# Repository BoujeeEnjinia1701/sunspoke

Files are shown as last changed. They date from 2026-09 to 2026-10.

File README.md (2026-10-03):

# SunSpoke

     

**Area:** Mobility and Logistics · **TRL:** 3 of 9 (proof of concept on paper) · **Value-engineering target:** USD 250 for the bike kit (estimated USD 208; solar set costed separately; pack priced in SwapCell) · **Difficulty:** 3 of 5

Open, bolt-on electric conversion kit for existing steel bicycles, serviceable by local bike mechanics and charged from a single 100 W solar panel or a shared village hub, using a SwapCell-compatible battery.

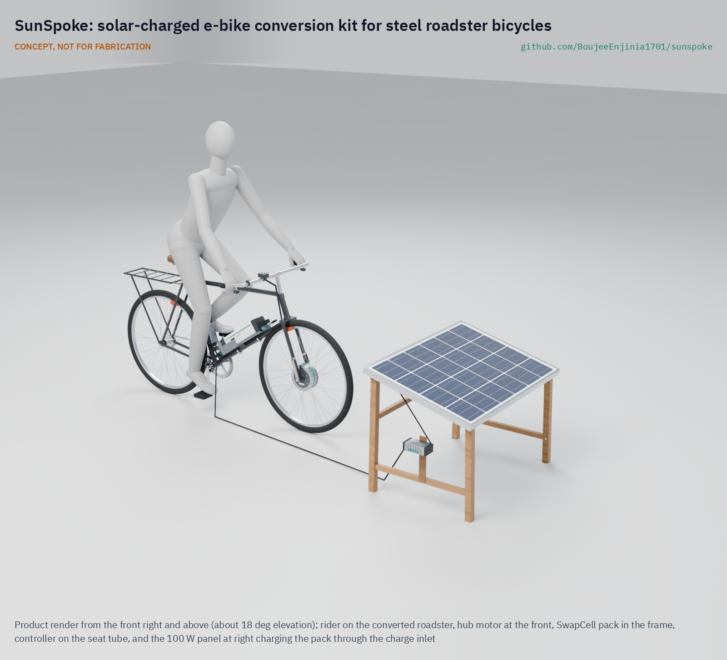
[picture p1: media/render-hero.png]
SunSpoke: solar-charged e-bike conversion kit for steel roadster bicycles, product render


[Exploded render](media/render-exploded.png) · [Detail render](media/render-detail.png) · [Interactive 3D model](media/viewer.html) · [Concept blueprint (PDF)](media/concept-blueprint.pdf) · [General arrangement SSP-DWG-001 (PDF)](cad/drawings/SSP-DWG-001.pdf) · [Sizing note SSP-CAL-001](docs/04-calcs/01-sizing.md) · [Prototype build plan](docs/05-build-plan.md) · [Design decisions](docs/06-design-decisions.md) · [Review note](docs/REVIEW.md)

## Concept rationale

The cheapest vehicle a rural household can electrify is the one it already owns. A bolt-on front hub kit leaves the roadster's chain, rear brake and carrier untouched, so the bicycle keeps working as a bicycle if anything electrical fails, and the parts that do fail are generic e-bike parts that a roadside mechanic can swap with spanners and a multimeter. Charging from one 100 W panel, or by swapping a shared SwapCell pack at a village hub, removes the dependence on a grid that many riders do not have.

Keeping the design open matters for the same reason. Closed kits lock the local mechanic out of repairs and settings; published drawings, a priced bill of materials and a plain wiring scheme let a workshop fit, service and adapt the kit, and let a small fabricator make the cradle and panel stand locally. Every part is chosen so the conversion can be done in a garage with hand tools and no welding.

## Burning platform

In 2023, 666 million people still had no access to electricity, and 85 percent of them, about 566 million, lived in sub-Saharan Africa ([World Bank, Tracking SDG 7: The Energy Progress Report 2025](https://www.worldbank.org/en/news/press-release/2025/06/25/energy-access-has-improved-yet-international-financial-support-still-needed-to-boost-progress-and-address-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)). Eighteen of the 20 countries with the largest access deficits are in that region. These are the same places where the unpowered steel roadster is the working vehicle for carrying people, water and produce over dirt roads.

For these riders, an e-bike that must be charged from a wall socket is not an option, and a new e-bike costs far more than the bicycle they already have. Assist that runs on a small solar panel and fits the existing bicycle turns hours of pushing a loaded bike uphill into a ride, without waiting for the grid to arrive.

## Where it could be used

### By industry

| Industry | Use |
| --- | --- |
| Smallholder agriculture | Carrying produce, feed and water from farm to market on loaded roadsters |
| Community health services | Longer, more reliable daily rounds for health workers on rural routes |
| Informal transport | Bicycle taxis and goods carriers that already run on roadsters |
| Bicycle repair and retail | A new fitting and service trade for roadside mechanics |
| Off-grid energy | Village solar hubs that charge and swap SwapCell packs as a service |
| Last-mile logistics | Low-cost cargo delivery in towns where grid charging is unreliable |

### By country or region

| Country or region | Why it matters there |
| --- | --- |
| Uganda and Kenya | Uganda's *Daily Monitor* reports that the boda-boda began with bicycle riders in Busia, on the Kenya-Uganda border, who called "border, border" to find passengers before the trade moved to motorcycles ([Daily Monitor, 2017](https://www.monitor.co.ug/uganda/news/national/boda-boda-makes-its-way-to-oxford-advanced-learners-dictionary-1702836)); an assist kit fits the bicycle taxis and carriers that started that trade |
| Wider sub-Saharan Africa | The region is home to 85 percent of the 666 million people without electricity and holds 18 of the 20 largest national access deficits ([World Bank, 2025](https://www.worldbank.org/en/news/press-release/2025/06/25/energy-access-has-improved-yet-international-financial-support-still-needed-to-boost-progress-and-address-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)); solar charging suits routes far from the grid |
| India | Bicycle-owning households rose from 84 million in 2001 to 111 million in 2011, and an estimated 21 percent of rural work trips are made by bicycle ([TERI, *Benefits of Cycling in India*, 2020](https://www.teriin.org/sites/default/files/2020-06/benefits-cycling-report.pdf), drawing on Census of India data); rural riders are a large base for a low-cost conversion |
| Haiti | The electricity access rate was estimated at about 47.1 percent in 2021, and the World Bank is financing solar mini-grids and standalone solar systems to extend access ([World Bank, 2024](https://www.worldbank.org/en/news/press-release/2024/10/18/world-bank-to-support-sustainable-energy-access-in-haiti)); a kit that charges from its own panel does not wait for the grid |
| Netherlands | About 56 percent of the 804,000 new bicycles sold in 2023 were e-bikes ([BOVAG and RAI Vereniging, February 26, 2024](https://www.bovag.nl/pers/persberichten/fietsbranche-consolideert-hoge-omzetniveau); also reported by [DutchNews.nl](https://www.dutchnews.nl/2024/11/the-dutch-are-cycling-more-and-buying-more-e-bikes/)); a conversion kit lets owners of sturdy older bicycles join that shift without buying new |

## What sparked the idea

The idea traces back to the first patented electric bicycle. On December 31, 1895, Ogden Bolton Jr. was granted US Patent 552,271 for an "electrical bicycle" with a direct-current motor built into the hub of the rear wheel ([Google Patents, US552271A](https://patents.google.com/patent/US552271A/en)). The hub motor was the first answer to adding power to a bicycle without redesigning it, and more than a century later it is still the simplest one: a motor that replaces a wheel and bolts into the frame the rider already owns. SunSpoke takes that precedent to the steel roadsters of rural Africa, with a motor a local mechanic can lace into a standard rim and a battery that charges from the sun.

## Problem

Most bicycles in rural Africa are unpowered steel roadsters, and commercial e-bikes are too costly and hard to charge where grid power is scarce. Design with, not for: requirements must come from co-design sessions and field trials with the intended users through a local partner.

## Concept

Open, bolt-on electric conversion kit for existing steel bicycles, serviceable by local bike mechanics and charged from a single 100 W solar panel or a shared village hub, using a SwapCell-compatible battery.

Full design precis: [docs/02-concept.md](docs/02-concept.md)

## Key components

- 250 W geared front hub motor wheel, 48 V
- 48 V SwapCell pack (SwapCell interface v0.3; 48 V decided by Amish, 2026-09-25)
- Sealed controller with a motor thermistor input that derates instead of cutting out (decided by Amish, 2026-09-25)
- Handlebar power switch in the SwapCell INTERLOCK loop
- Pedal-assist sensor
- SwapCell receiver cradle on V-saddles and three band clamps (no welding or drilling), with a drop-down gate and over-centre draw latch, and the host adapter
- 100 W solar panel with MPPT charger
- Weatherproof wiring harness

The working bill of materials is in [bom/bom.csv](bom/bom.csv).

## Building the prototype

The [prototype build plan](docs/05-build-plan.md) (SSP-BLD-001) shows, in pictures drawn from the model, how each part is made and how it fits the next, then how the kit goes onto a donor roadster in twelve steps and the solar set in three. Making the design buildable changed the concept in places (decision record [SSP-DDR-003](docs/decisions/0003-design-for-construction.md)): the cradle now sits on V-saddles with three band clamps, the pack is held by a drop-down gate and an over-centre draw latch, the torque arms are joggled to lie on the fork blades, and the panel stand is a bolted timber frame. Nothing is welded, and nothing is drilled or cut on the donor bicycle. Decisions still open are in the [design decisions register](docs/06-design-decisions.md).

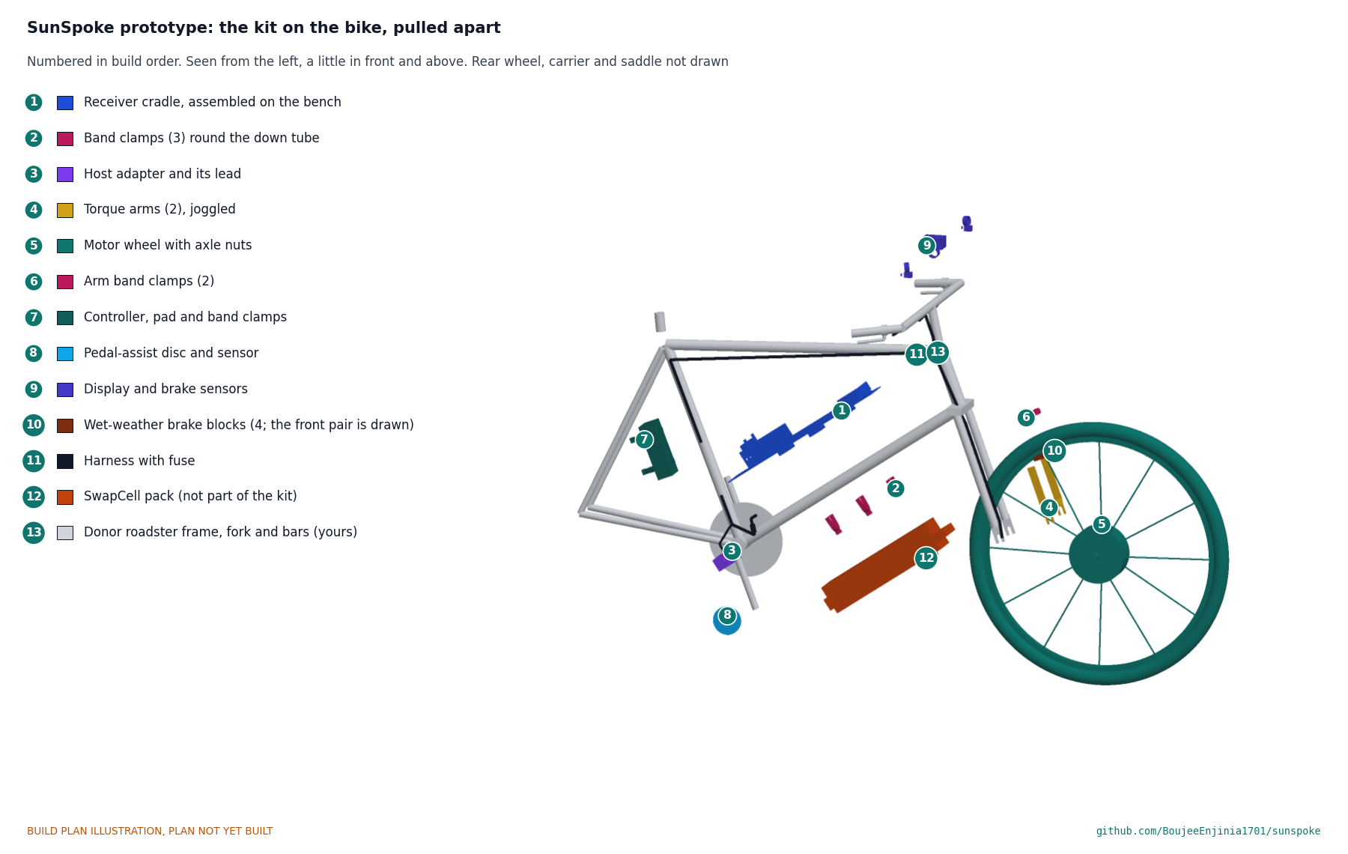
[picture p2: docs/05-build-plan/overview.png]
SunSpoke kit on the donor bicycle, pulled apart and numbered in build order


## Safety

> Check that the donor frame and fork can take a hub motor's torque; fit torque arms, and never file the fork's dropout slots: choose a donor whose slots take the motor's axle flats. Rod brakes on steel rims lose most of their grip in rain; fit the wet-weather brake blocks in the kit, and do not ride a trial bike in the wet until a wet braking test meets the target. Contains a lithium battery pack. Use a BMS with cell-level protection, fuse the pack, and charge on a non-combustible surface.

## Repository layout

| Folder | Contents |
| --- | --- |
| `docs/` | Problem, concept, requirements, calculations and design decisions |
| `cad/src/` | build123d Python source, the source of truth for all geometry |
| `cad/step/`, `cad/stl/` | Exported models for FreeCAD, other CAD tools and printing |
| `cad/drawings/` | 2D sketches and dimensioned drawings |
| `bom/` | Bill of materials |
| `electronics/` | KiCad schematics and PCB layouts |
| `firmware/` | Microcontroller code |
| `media/` | Renders, perspectives and photos |
| `build-log/` | Dated prototyping notes |

## Documentation

Controlled documents follow the portfolio [documentation standard](.kit/STANDARDS.md). Each carries a document ID (SSP-PRC-001 for the precis), a version and a revision history. Branded PDFs are built with `python .kit/render.py` and attached to GitHub Releases when a document is tagged, for example `SSP-PRC-001/v1.0`.

## Credits

Designed by Amish Chadha. See [CONTRIBUTORS.md](CONTRIBUTORS.md) for roles. To cite this design, use [CITATION.cff](CITATION.cff) (GitHub shows it as "Cite this repository").

AI assistance (Claude) was used to accelerate concept renders, prototype documentation and first-pass sizing calculations. Design direction and all decisions are Amish Chadha's, recorded in this repository's decision records (`docs/decisions/`).

## Licenses

- **Hardware** (CAD, drawings, BOM, electronics): [CERN-OHL-S v2](LICENSE)
- **Software** (firmware, scripts, notebooks): [MIT](LICENSE-SOFTWARE)

A project of the [Design Molecule](https://designmolecule.com) lab.

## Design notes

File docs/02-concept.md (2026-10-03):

---
doc_id: SSP-PRC-001
title: SunSpoke design precis
project: SunSpoke
doc_type: Design precis
version: "0.7"
status: Draft
date: '2026-10-02'
author: Amish Chadha
license: CERN-OHL-S-2.0
revisions:
- version: "0.1"
  date: '2026-09-24'
  author: Amish Chadha
  change: Initial scaffold
- version: "0.2"
  date: '2026-09-24'
  author: Amish Chadha
  change: Populate to TRL 2 (architecture, first-order numbers, fork torque, safety, media)
- version: "0.3"
  date: '2026-09-25'
  author: Amish Chadha
  change: TRL 3. Record Amish's decisions (SSP-DDR-001), build to SwapCell interface v0.3 (items W, C, V), numbers checked against SSP-CAL-001, parametric model and GA drawing SSP-DWG-001
- version: "0.4"
  date: '2026-09-25'
  author: Amish Chadha
  change: Recommendations accepted by Amish (DDR-002)
- version: "0.5"
  date: '2026-10-01'
  author: Amish Chadha
  change: "Constructable design (SSP-DDR-003): cradle on V-saddles with three band clamps, drop-down gate and draw latch, joggled torque arms, timber panel stand; figures from SSP-CAL-001 v0.3; build plan SSP-BLD-001"
- version: "0.6"
  date: '2026-10-02'
  author: Amish Chadha
  change: "Region, slot filing, reference motor and wet braking decided by Amish on 2026-10-02 (SSP-DEC-001)"
- version: "0.7"
  date: '2026-10-02'
  author: Amish Chadha
  change: "Figures from SSP-CAL-001 v0.5: wet-weather brake blocks in the kit, wet stop 11.9 m with them against a proposed 14 m wet target, added mass 6.88 kg, bike kit USD 208"
---

# SunSpoke design precis

SunSpoke converts a steel roadster bicycle into a pedal-assist e-bike with a 48 V, 250 W geared front hub motor, a sealed controller and a SwapCell pack clamped inside the main triangle, all bolted on with no welding, and charges the pack from one 100 W solar panel or a shared village hub. The sizing note SSP-CAL-001 gives about 37 km of loaded range on one pack, about 315 Wh stored per 4.5 sun-hour day from one panel (about 27 km of loaded riding), 6.88 kg of added mass, and a bike kit costing about USD 208 in parts (USD 42 under its USD 250 value-engineering target), with the solar set (about USD 90) costed separately and the pack priced in SwapCell. No requirement is shown to be not met; motor heating on a long loaded climb (R3, now handled by a thermistor derate rather than a cutout), fork slot fit (R4) and stopping distance (R11) are at risk.

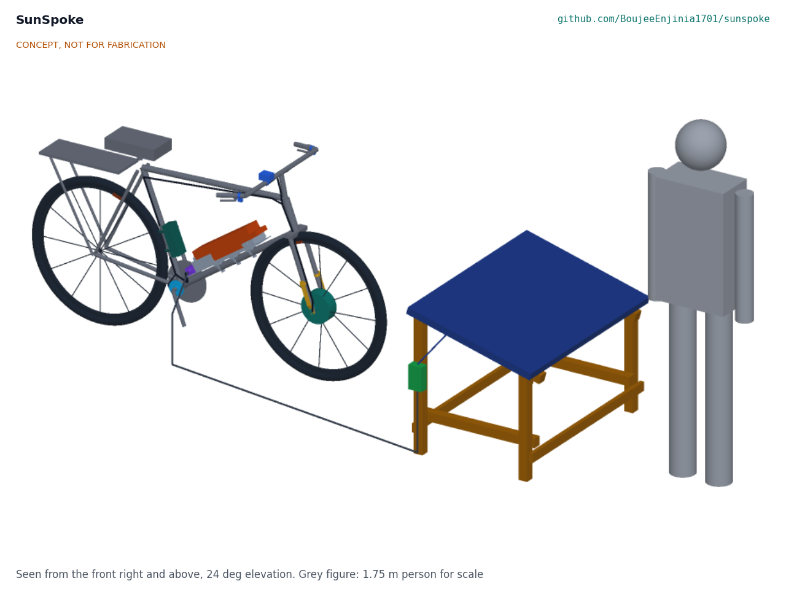
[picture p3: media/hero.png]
Hero render


*Figure 1. SunSpoke fitted to a 28 in roadster, with the 100 W solar charging set and a 1.75 m person for scale. Kit parts are colored; the donor bicycle is grey. Rendered from the parametric model `cad/src/model.py`.*

## How it works

1. **Charge.** A 100 W panel on a simple stand feeds a boost MPPT charger that raises the panel's roughly 18 V to the pack's charge voltage. A 5 m cable reaches the charge inlet on the host adapter, so the panel sits in sun while the bike and pack stay in shade. Alternatively the rider swaps the pack at a village hub that has a SwapCell dock.
2. **Store.** A SwapCell pack (13S2P, 46.8 V nominal, about 468 Wh) slides connector first down the receiver cradle on the down tube, and a drop-down gate closed by an over-centre draw latch preloads it against its end stop (SwapCell latch class V1). To swap it, the rider opens the latch, folds the gate down, slides the pack up the tube off its plug and lifts it out to the left.
3. **Wake and enable.** The cradle receptacle carries the 10 kΩ INTERLOCK coding resistor of SwapCell interface v0.3, in series with the handlebar power switch. Switching on closes the loop and wakes the pack with no supply from the bike. The pack enables legacy discharge after 2 s, which powers the host adapter; the adapter then sends the CAN heartbeat (mode 2). When the charger is connected the adapter, powered from the charge inlet, requests mode 3, or mode 4 (charge-discharge) if the bike is switched on.
4. **Sense.** A split-disc pedal-assist sensor at the crank detects pedaling. Magnetic sensors on both brake levers detect braking.
5. **Control.** A sealed 48 V, 15 A sine-wave controller on the seat tube drives the motor only while the rider pedals and no brake is applied, up to 20 km/h by default. It reads a thermistor in the motor winding and reduces current progressively from 110 °C so the winding never passes 120 °C; it never cuts assist abruptly on a climb. A handlebar unit sets the assist level, shows pack charge and has a 6 km/h walk-assist button. There is no throttle.
6. **Drive.** A 250 W geared hub motor, laced by a local mechanic into a standard 28 in (ETRTO 635) rim, replaces the front wheel. Torque arms on both fork blades carry the motor's reaction torque so it does not act on the thin dropouts alone.

Front drive leaves the roadster's chain, freewheel or coaster brake and rear carrier untouched, which is what makes a bolt-on fit and local repair realistic. If the host adapter fails, the pack still runs the bike in SwapCell legacy mode (discharge only, 15 A, the same as the controller limit), so the rider gets home.

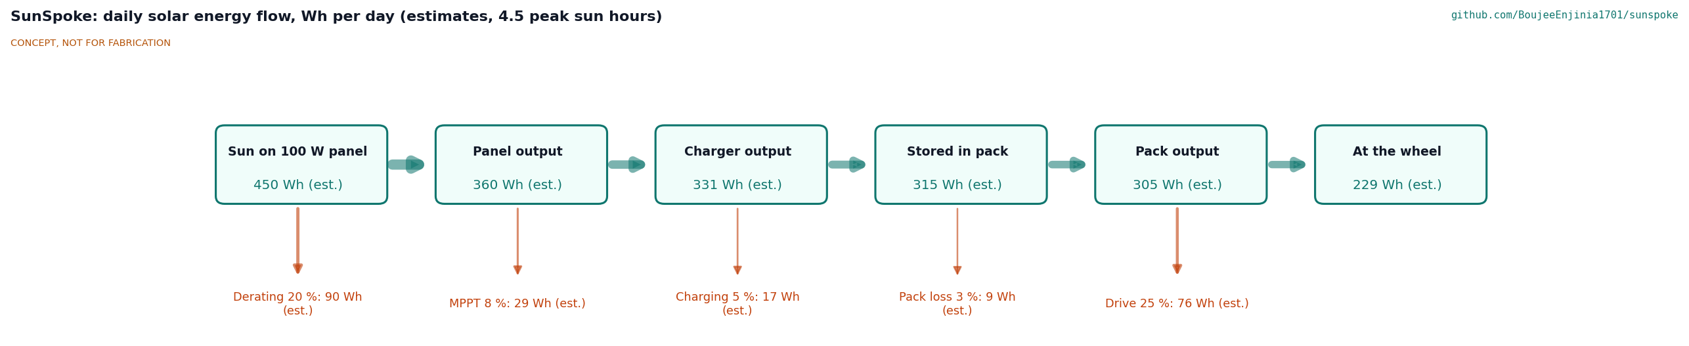
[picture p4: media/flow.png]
Energy flow


*Figure 2. Daily solar energy flow from one 100 W panel at 4.5 peak sun hours, in Wh per day. All values are estimates from SSP-CAL-001.*

## Main components

Numbers match the exploded view (Figure 3) and `bom/bom.csv`. The general arrangement is drawing SSP-DWG-001 (`cad/drawings/SSP-DWG-001.pdf`), generated from `cad/src/model.py`.

| # | Component | Choice | Notes |
| --- | --- | --- | --- |
| 1 | Front hub motor wheel | 48 V, 250 W geared hub, slow winding, 100 mm spacing, 10 mm axle flats, built-in 10 kΩ NTC winding thermistor, laced into a 28 in steel rim | Donor tyre and tube reused. Decided by Amish, 2026-09-25 |
| 2 | Torque arms | 5 x 20 mm steel arms, slotted to fit the axle flats and joggled 8 mm to lie on the blade, each held 130 mm up its fork blade by a band clamp | Mandatory on both sides; made locally (SSP-DWG-107) |
| 3 | Controller | 48 V, 15 A limit, sine-wave, potted or IP65, pedal-assist, brake cut-off, power-lock, walk-assist and motor thermistor inputs; derate from 110 °C; on a rubber pad on the seat tube, two band clamps | Generic part; thermistor input decided by Amish, 2026-09-25 (SSP-DDR-002) |
| 4 | SwapCell receiver cradle | Folded 3 mm aluminium tray with guides, on three rubber-lined V-saddles held by three band clamps; slide strips, catch bar, end stop with the receptacle and its 10 kΩ coding resistor; drop-down gate with an over-centre draw latch | Latch class V1 vehicle receiver; fits 28 to 32 mm down tubes; no welding or drilling (SSP-DDR-003) |
| 5 | Host adapter and charge port | Microcontroller with CAN transceiver, diode-OR supply from PACK+ and the charge inlet, controller power-lock output | SwapCell vehicle host for modes 2, 3 and 4 |
| 6 | SwapCell pack | 13S2P, about 468 Wh, 340 x 90 x 80 mm, about 2.85 kg | Priced once in SwapCell ($414); not in the kit cost |
| 7 | Pedal-assist sensor | Split 12-magnet disc and Hall sensor | Fits without pulling the crank |
| 8 | Handlebar control and brake cut-off | LED level and charge display, power switch in the INTERLOCK loop, walk-assist button, two clamp-on lever sensors | Works with rod or cable brake levers |
| 9 | Wiring harness | Keyed waterproof connectors, 20 A fuse, spiral wrap | Every joint pluggable (R9) |
| 10 | Solar panel | 100 W monocrystalline, about 1,000 x 670 mm | Costed separately; can be shared at a hub |
| 11 | Boost MPPT charger | 15 to 25 V in, CC/CV to 54.6 V at up to 2 A out | Generic; the host adapter is the SwapCell charge host |
| 12 | Panel stand | Bolted timber A-frame, 45 x 45 mm sawn timber, 15 degree tilt | Local make (SSP-DWG-108 to 110) |
| 13 | Charge cable | 5 m outdoor cable with keyed plug to the charge inlet | Pack charges in shade |

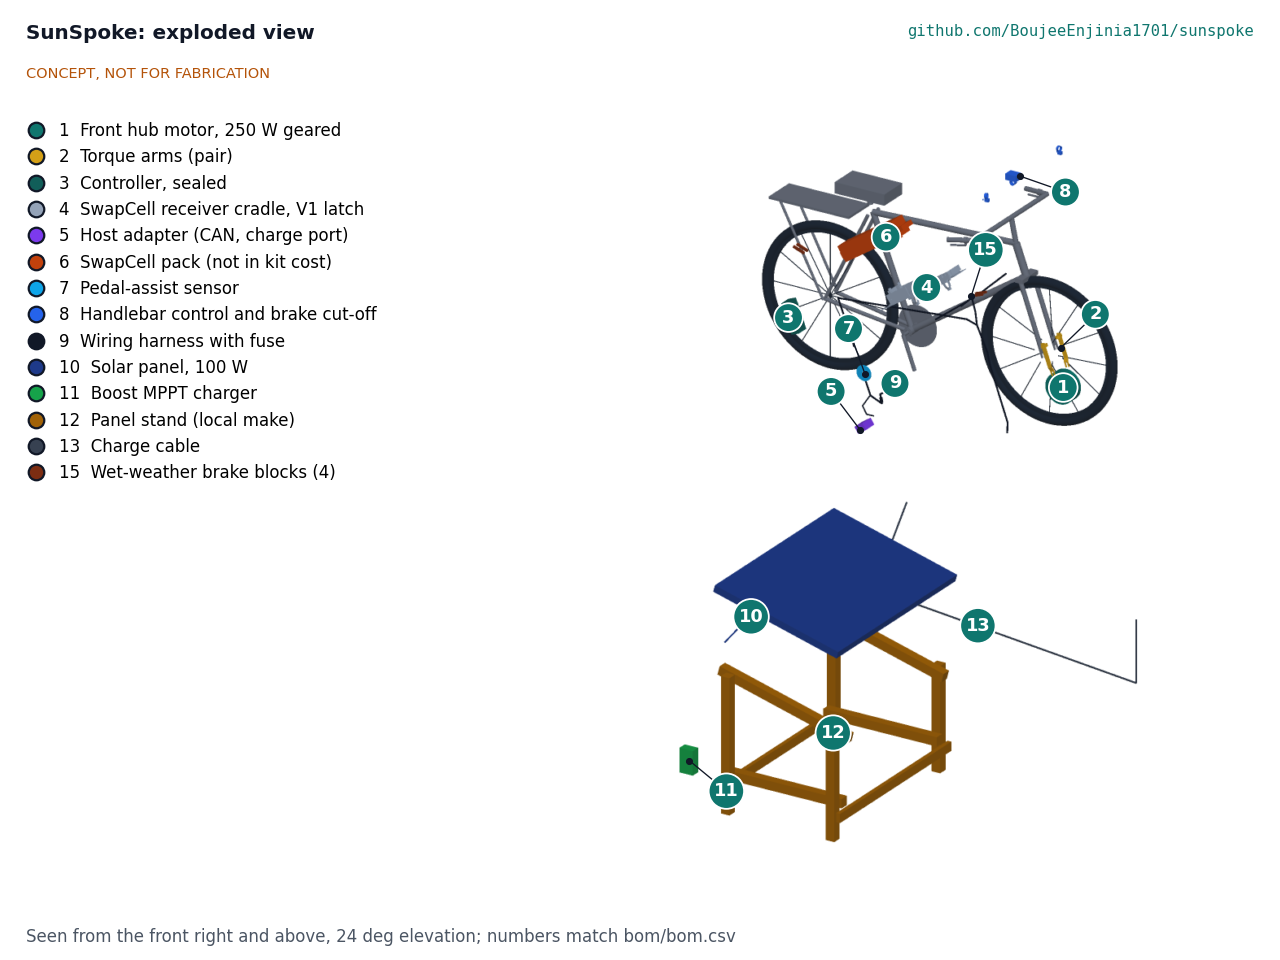
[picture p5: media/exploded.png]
Exploded view


*Figure 3. Exploded view with numbered callouts matching the BOM. The solar charging set is shown displaced below the bike.*

## Key numbers

All values come from SSP-CAL-001 (`docs/04-calcs/sizing.py`) and are paper estimates. The design load case is 128.88 kg (75 kg rider, 25 kg cargo, 22 kg roadster, 6.88 kg of kit and pack) on a dry dirt road.

| Quantity | Value | Basis | Requirement |
| --- | --- | --- | --- |
| Pack energy, design case | about 11.3 Wh/km | Crr 0.02, CdA 0.6 m², 18 km/h, 30 % allowance, rider 70 W, drive 75 % | |
| Range on SwapCell | about 37 km design (36 with minimum cells); 75 km light; 23 km with 80 kg cargo | 419 Wh usable | R2 met |
| Motor on the 8 % grade at 8 km/h | 204 W and 32.6 N·m (81 % of a 40 N·m peak) | 127.7 N, rider 80 W | R3 met on power |
| Motor winding, top of 500 m at 35 °C | about 100 °C base case; about 139 °C hot case | Lumped thermal model | R3 **at risk** |
| Thermal derate from 110 °C | Starts after 694 m (base) or 224 m (hot) of the 8 % climb; sustained 4.7 or 3.7 km/h on an unending climb | Winding held at 120 °C, rider 80 W | R3 |
| Added mass | 6.88 kg (kit 4.03, pack 2.85) | Table 2 of SSP-CAL-001 | R6 met, 0.12 kg margin |
| Solar, one 100 W panel | 315 Wh/day stored (280 at 4 h); about 27 km of loaded riding per day | 20 % derating, 92 % MPPT, 95 % charging | R8 met |
| Recharge 10 to 100 % | 1.3 days (1.5 at 4 h) | 421 Wh / 315 Wh per day | R8 met |
| Peak charge current | 1.47 A (0.15C); 1.39 A net in mode 4 | 74 W into about 50 V | R13 |
| INTERLOCK node | 0.30 V, 30 µA | 10 kΩ against a 100 kΩ pull-up | R13 |
| Torque arms | 154 N per clamp; 60 MPa in the arm, safety factor 4.2 | 40 N·m peak at 130 mm | R10 |
| Dropout slot filing | about 0.24 mm per side on a 9.53 mm slot | 10 mm flats | R4 **at risk** |
| Cradle retention at 25 g | Axial margin 7.7; rotation margin 1.44 | 3.5 kg pack plus 1.10 kg cradle, three band clamps over V-saddles | R13, not verifiable |
| Pack fit in the triangle | 121 mm clearance; 165 mm free travel for removal (143 needed); removal path checked against every cradle part | Parametric model, pack at 48 % of the down tube | R5 met on paper |
| Stopping from 20 km/h | 8.5 m dry; 21.8 m wet with standard blocks, 11.9 m wet with wet-weather blocks (assumed friction 0.25) | Rod brakes on steel rims, 0.5 s delay | R11 **at risk** |
| Bike kit cost | about USD 208, USD 42 under the USD 250 value-engineering target | Items 1 to 5, 7 to 9, 14, 15 | R12 met |
| Solar set cost | about USD 90 | Items 10 to 13, costed separately | |
| SwapCell pack | $414, priced in SwapCell (SWC-CAL-001) | Excluded from the kit | |

### Fork and frame torque

The motor pushes against its own axle. At the assumed 40 N·m peak, the axle flats would load each bare dropout face with about 4 kN, enough to spread or crack thin stamped dropouts over time. Torque arms move the reaction to clamps 130 mm up each blade, about 154 N each. Roadster slots are often 3/8 in (9.53 mm), so the 10 mm flats may need about 0.24 mm filed from each face; whether that is acceptable with torque arms fitted is open (SSP-DDR-001 item 15). Braking and pothole loads also rise with the heavier front wheel and higher speed; the fork's fatigue margin is unverified.

## Key design choices

All of these were decided by Amish on 2026-09-25 (go with recommendation), in SSP-DDR-001 or SSP-DDR-002.

- **48 V on the SwapCell pack (Option A).** Meets R2, shares packs and docks with other portfolio vehicles and keeps the pitch. A 36 V kit with its own generic pack (Option B) is kept only as a later low-cost variant.
- **Budget covers the bike kit.** `budget_usd` stays at USD 250, a value-engineering target, and R12 applies to the bike kit (about USD 208); the solar set is costed separately and the pack is priced once in SwapCell.
- **Front geared hub motor.** Leaves the drivetrain, rear brake and carrier untouched and is the easiest bolt-on.
- **Pack in the main triangle on the down tube.** Keeps the rear carrier free and the mass low and central.
- **Motor laced locally into a 28 in rim**, with a lacing card.
- **Assist cut-off 20 km/h by default**, adjustable only by the mechanic and never above 25 km/h. SSP-CAL-001 shows the loaded bike stops in about 8.5 m from 20 km/h but about 12.4 m from 25 km/h on dry dirt.
- **Pedal assist only, plus a 6 km/h walk assist.** No throttle.
- **Charge on the bike.** The charger plugs into the host adapter's charge inlet and the adapter acts as the SwapCell charge host; hub docks remain an option.
- **SwapCell interface v0.3 items W, C and V.** The cradle fits the 10 kΩ coding resistor (W), the adapter uses mode 4 when the bike is on while charging (C), and the cradle is a latch class V1 receiver (V).
- **Power switch in the INTERLOCK loop, adapter powered from legacy discharge or the charge inlet.** Decided by Amish, 2026-09-25: go with recommendation (SSP-DDR-002). Switching off opens the pack output, a hard off that needs no electronics on the bike.
- **Controller with a motor thermistor input (R3).** Decided by Amish, 2026-09-25: go with recommendation (SSP-DDR-002). The motor carries a winding thermistor and the controller derates from 110 °C instead of cutting out.

## Safety

> **Safety:** SunSpoke carries a lithium-ion pack of about 468 Wh, drives a loaded bicycle faster than its rider alone, and puts new loads on an old steel fork. Treat each of these as a hazard at every stage.

- **Lithium pack.** A cell in thermal runaway vents flammable, toxic gas and can ignite its neighbors. Use only a SwapCell pack with its BMS, fuse the harness (item 9), charge on a non-combustible surface in shade and away from sleeping areas, never charge a pack that is damaged, swollen or has been submerged, and keep the pack out of direct sun when parked. The pack refuses charge below 0 °C and above 45 °C cell temperature.
- **Pack retention.** A pack that leaves its cradle at speed is a 2.85 kg projectile with live contacts. The cradle must meet SwapCell latch class V1, the draw latch must have its safety catch engaged, and the three band clamps must be tightened to their stated torque and checked at every service; rotation resistance at a 25 g lateral shock has only about 1.44 margin on paper.
- **Fork dropout failure.** A spun axle can rip the motor cable and let the wheel leave the fork, which throws the rider over the bars. Torque arms on both sides are mandatory, axle nuts need a set torque and a check at every service, and a fork with cracked, bent or heavily filed dropouts must not be converted. Fork fatigue under the heavier wheel is unverified.
- **Braking with added speed and mass.** At 20 km/h the loaded bike carries about 2.0 kJ, about 2.5 times the unconverted bike at 13 km/h. Rod brakes on steel rims lose most of their grip in rain: about 22 m to stop from 20 km/h wet against 8.5 m dry; with the wet-weather blocks, assuming a friction of 0.25, the wet stop is about 11.9 m, inside a proposed wet target of 14 m. Brake cut-off sensors on both levers, the 20 km/h limit, and a brake check at fitting with new wet-weather blocks suited to steel rims are part of the kit (decided 2026-10-02). R11 now has a wet stopping target, and no trial is ridden in the wet until a wet braking test meets it (SSP-DEC-001). Braking with only the front brake on loose ground can wash out the front wheel.
- **Motor overheating.** On a long loaded climb in the heat the winding may exceed its limit (R3). A sudden cutout on a hill can stall a loaded bike, so the controller derates on the motor thermistor instead (decided, SSP-DDR-002); the bike slows to walking pace on a very long hot climb but keeps moving.
- **Wiring in rain.** The system is about 50 V DC, below the usual touch-safety threshold, but water in connectors causes corrosion, shorts and sudden loss of assist. Use keyed IP65 connectors with dielectric grease, drip loops, and routing that keeps the motor cable exit facing down. The fuse protects against a pinched cable shorting to the frame. Opening the power switch opens the pack output within 1 ms.
- **Traction.** With cargo on the rear carrier, the front wheel carries little weight and a front motor can spin on sand or wet laterite. Assist ramp-up must be soft.

## Open questions

These remain after SSP-DDR-001. None of them is TRL 4 work to be started now; TRL 4 is on hold by Amish's instruction.

- First partner and region for co-design and fitting trials. Decided 2026-10-02: western Kenya and eastern Uganda as the default region, with a bicycle mechanics' group or rural transport organization there as the partner type; the partner is named when the portfolio picks partners for this area (SSP-DEC-001).
- Slot filing (R4). Decided 2026-10-02: never file the fork for now; choose donors whose slots take 10 mm flats, and if the donor survey shows 3/8 in slots are the norm, look first for a motor whose axle flats fit them (SSP-DEC-001).
- Motor data for R3: winding resistance, thermal capacity and gear temperature limit. Decided 2026-10-02: the reference motor is a widely sold 250 W front geared hub such as one of Bafang's; its maker is asked for the data and R3 is rerun, and the winding resistance is measured at TRL 4 if the data are not published (SSP-DEC-001).
- Wet braking: decided 2026-10-02, R11 adds a wet stopping target (proposed value 14 m from 20 km/h, awaiting Amish), wet-weather brake blocks suited to steel rims go in the kit, and trials keep a no-wet-riding rule until a wet braking test meets the target (SSP-DEC-001).
- The legacy-to-heartbeat transition in the SwapCell pack. Raising it with the SwapCell project is decided (SSP-DDR-002); the change belongs to that repo.
- Confirm that a low-cost boost charger with input-voltage tracking gives near-MPPT yield from one 18 V panel.

Concept media: [blueprint sheet](../media/concept-blueprint.pdf), [interactive 3D model](../media/viewer.html).

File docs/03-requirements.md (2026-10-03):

---
doc_id: SSP-REQ-001
title: SunSpoke requirements
project: SunSpoke
doc_type: Requirements
version: "0.7"
status: Draft
date: '2026-10-02'
author: Amish Chadha
license: CERN-OHL-S-2.0
revisions:
- version: "0.1"
  date: '2026-09-24'
  author: Amish Chadha
  change: Initial scaffold
- version: "0.2"
  date: '2026-09-24'
  author: Amish Chadha
  change: First measurable requirements for TRL 2
- version: "0.3"
  date: '2026-09-25'
  author: Amish Chadha
  change: Record SSP-DDR-001 (R1 20 km/h default and walk assist, R12 redefined to the bike kit, new R13 for SwapCell interface v0.3); status column from SSP-CAL-001
- version: "0.4"
  date: '2026-09-25'
  author: Amish Chadha
  change: Recommendations accepted by Amish (DDR-002)
- version: "0.5"
  date: '2026-10-01'
  author: Amish Chadha
  change: Status values from SSP-CAL-001 v0.3 for the constructable design (SSP-DDR-003); R12 reported against the value-engineering target
- version: "0.6"
  date: '2026-10-02'
  author: Amish Chadha
  change: "R11 adds a wet stopping target, decided by Amish on 2026-10-02 (SSP-DEC-001)"
- version: "0.7"
  date: '2026-10-02'
  author: Amish Chadha
  change: "Status values from SSP-CAL-001 v0.5: R11 wet stop with wet-weather blocks and a proposed wet target of 14 m; R6 6.88 kg; R12 USD 208; no requirement changed status"
---

# SunSpoke requirements

These requirements were checked by calculation in SSP-CAL-001 at TRL 3. None is shown to be not met; R3, R4 and R11 are at risk, and R7, R9, R10 and R13 cannot be verified until hardware exists (TRL 4, on hold by Amish's instruction). Targets are not yet validated with users and will be revised after co-design sessions (see SSP-PRB-001). Changes in v0.3 follow Amish's decisions of 2026-09-25 (SSP-DDR-001). In v0.5 the status values follow SSP-CAL-001 v0.3 for the constructable design (SSP-DDR-003); no requirement changed status. In v0.6, R11 adds a wet stopping target (SSP-DEC-001, 2026-10-02). In v0.7, the values follow SSP-CAL-001 v0.5 (wet-weather blocks, 6.88 kg, USD 208); no requirement changed status. In v0.4, R3 is restated to require a thermal derate instead of a cutout and R10 adds the handlebar power switch in the INTERLOCK loop (SSP-DDR-002).

The **design load case** used throughout is a 75 kg rider, 25 kg of cargo on the rear carrier, a 22 kg roadster and about 6.88 kg of kit and pack: about 130 kg (128.88 kg) in total, on a dry dirt road.

*Table 1. Requirements with status from SSP-CAL-001.*

| ID | Requirement | Target | Verification (TRL 3 or later) | Status (SSP-CAL-001) |
| --- | --- | --- | --- | --- |
| R1 | Pedal-assist power within pedelec limits | 250 W rated continuous motor output; pedal assist only, no throttle, plus a 6 km/h walk assist; assist cuts off at 20 km/h by default, adjustable only by the mechanic and never above 25 km/h | Motor and controller datasheets; controller settings | Met (by specification) |
| R2 | Range per charge in the design load case | 30 km or more on a dirt road with the rider pedaling at about 70 W | Energy calculation; later field ride with a logger | Met (37 km) |
| R3 | Climb a loaded hill | 8 % grade for 500 m at 8 km/h or more in the design load case, rider at 80 W, at 35 °C ambient; the controller derates motor current on a winding thermistor from 110 °C so the winding stays at or below 120 °C, and never cuts assist abruptly | Force and thermal calculation; later hill test | At risk |
| R4 | Fit to the donor bike without fabrication | No welding, drilling or cutting of the frame or fork; fitted in 90 min or less by a trained local mechanic with basic tools (spanners to 18 mm, hex keys, spoke key, screwdriver, file) | Fitting sequence review; later timed fitting trials | At risk |
| R5 | Fit the common roadster | 28 in (ETRTO 635) front wheel, 100 mm front dropout spacing, round down tube 28 to 32 mm, rod or cable brakes | Survey of donor bikes with the partner; model check | Met (on paper) |
| R6 | Keep the bike rideable and liftable | Added mass 7 kg or less including the pack; bike still stands on its kickstand and can be pushed with the system off | Mass estimate; later weighing | Met (6.88 kg) |
| R7 | Survive dust, rain and heat | Controller, host adapter and connectors IP65; motor IP54 or better; ride through heavy rain and 150 mm of standing water; operate at 0 to 45 °C ambient | Datasheets and design review; later spray and dust tests | Not verifiable at TRL 3 |
| R8 | Charge from one 100 W solar panel | Energy for 20 km or more of loaded assist per day at 4.5 peak sun hours; full recharge (10 to 100 %) of the pack in 2 days or less | Solar yield calculation | Met (27 km/day, 1.3 days) |
| R9 | Repairable by a local mechanic | Every electrical joint pluggable with keyed connectors; any single kit part swapped in 20 min or less at the roadside; basic faults diagnosed with a multimeter and a printed fault chart; 70 % or more of kit cost in generic parts available in regional towns | Design review; parts availability survey with the partner | Not verifiable at TRL 3 (84 % generic) |
| R10 | Safe assist control | Brake cut-off on both brake levers; assist stops within 0.5 s of braking or of pedaling stopping; pack output fused; torque arms on both fork dropouts; a handlebar power switch in series with the INTERLOCK coding resistor opens the pack output when switched off | Design review; later bench test | Not verifiable at TRL 3 |
| R11 | Stop safely with the added mass and speed | Design load case stops from 20 km/h in 9 m or less on a dry dirt road, and meets a wet stopping target on a wet dirt road (added 2026-10-02, SSP-DEC-001; proposed value 14 m from 20 km/h, awaiting Amish, to be confirmed with the wet-weather blocks' data) | Braking calculation; later field tests dry and wet with wet-weather brake blocks for steel rims | At risk (8.5 m dry; 21.8 m wet with standard blocks; 11.9 m wet with wet-weather blocks at an assumed friction of 0.25, against a proposed 14 m target) |
| R12 | Affordable | Bike conversion kit (items 1 to 5, 7 to 9, 14, 15) $250 or less in parts; the solar charging set is costed separately; the SwapCell pack is excluded and priced once in SwapCell | Priced BOM (`bom/bom.csv`) | Met (USD 208, USD 42 under the USD 250 value-engineering target) |
| R13 | Build to SwapCell interface v0.3 | Cradle receptacle fits the 10 kΩ ±1 % INTERLOCK coding resistor (item W); host adapter acts as the vehicle host for modes 2, 3 and 4 within the pack's published limits (item C); cradle is a latch class V1 vehicle receiver with at least 330 N preload (item V) | Design review against SWC-PRC-001 v0.3; later vibration and shock test | Not verifiable at TRL 3 |

## Assumptions

- Rolling resistance coefficient about 0.02 on a dry dirt road; drag area about 0.6 m² for an upright rider with cargo.
- The rider supplies about 70 W while cruising and 80 W on a climb.
- 4.5 peak sun hours per day is a mid-range value for most of sub-Saharan Africa outside the rainy season; 4 hours is used as the low case.
- Pack capacity follows SwapCell interface v0.3 and SWC-CAL-001 (about 466 Wh at 0.2C, 90 % usable). The 48 V system on SwapCell is decided (SSP-DDR-001); a 36 V kit is only a later low-cost variant.
- The 25 km/h ceiling follows EU pedelec practice (Regulation (EU) No 168/2013 excludes pedal cycles with assist up to 250 W that cuts off at 25 km/h; EN 15194 is the matching product standard). The 20 km/h default is decided (SSP-DDR-001) and is supported by the braking result in SSP-CAL-001.
- R12 covers only the bike kit, and its USD 250 is the value-engineering target (`budget_usd`), a hypothetical control target rather than a spending limit. The solar set (about USD 90) is costed separately because a rider who charges at a village hub does not need it.

> **Safety:** R6, R10, R11 and R13 are safety requirements for a bicycle carrying a 468 Wh lithium-ion pack at up to 20 km/h. Braking in the wet (about 22 m from 20 km/h in SSP-CAL-001) falls far short of the dry target, and pack retention and fork loads are unverified. Since 2026-10-02 R11 carries a wet target, the kit includes wet-weather brake blocks suited to steel rims, and no trial is ridden in the wet until a wet braking test meets the target (SSP-DEC-001). No conversion may be ridden before these are verified by test, which is TRL 4 work and on hold.

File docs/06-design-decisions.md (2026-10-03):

---
doc_id: SSP-DEC-001
title: SunSpoke design decisions register
project: SunSpoke
doc_type: Design decisions register
version: "0.3"
status: Draft
date: '2026-10-02'
author: Amish Chadha
license: CERN-OHL-S-2.0
revisions:
  - version: "0.1"
    date: '2026-10-01'
    author: Amish Chadha
    change: Register opened with the build plan; open decisions from the decision records, the review note and the design for construction
  - version: "0.2"
    date: '2026-10-02'
    author: Amish Chadha
    change: "Amish approved the recommendations for all eleven open decisions (SSP-DDR-003 accepted); moved to decisions made; To confirm items 1 and 2 updated"
  - version: "0.3"
    date: '2026-10-02'
    author: Amish Chadha
    change: "Approved follow-ups: wet-weather brake blocks added to the BOM (line 15) and the model; wet stopping distance calculated; Value engineering section updated (bike kit USD 208); To confirm item 11 added (wet target value and block friction)"
---

# SunSpoke design decisions register

Every design decision still to be made, and every decision made, in one place. Each decision is argued in full in its decision record under `docs/decisions/` or in the review note; this register is the index Amish works from. The build plan (`docs/05-build-plan.md`) describes the design as it stands and does not list open decisions.

## Open decisions

None. All open decisions were decided on 2026-10-02.

## To confirm when parts are bought

| # | What to confirm | Why it matters | Source |
| --- | --- | --- | --- |
| 1 | The motor's axle has 10 mm flats (or, if the donor survey shows 3/8 in slots are the norm, flats that fit them; decided 2026-10-02), an M12 thread and enough length for three threads past the nut over the dropout, torque arm and washer | The torque arms and dropouts are sized to it | SSP-DDR-003, P7 |
| 2 | The donor's dropout slots take the 10 mm flats without filing (never file the fork, decided 2026-10-02), its down tube is round and 28 to 32 mm, and the step from dropout face to blade outside is about 8 mm | The saddles, torque arm slot and joggle are sized to these | SSP-DDR-003, P1 and P7 |
| 3 | The donor's bottom bracket is cup-and-cone with a left lockring | The pedal-assist bracket fits under it | SSP-DDR-003, P9 |
| 4 | The draw latch: adjustable hook, safety catch, 500 N working load or more, over centre with 50 N or less at its lever | It sets the V1 preload of 330 N | SSP-DDR-003, P4; SSP-CAL-001 section 8 |
| 5 | The band clamp torque that gives 1.5 kN of band tension | The cradle retention margins assume it | SSP-CAL-001 section 8 |
| 6 | The SwapCell receptacle's flange and hole pattern | The end stop's four holes are drawn for a 37 x 24 mm pattern | SSP-DDR-003, P3 |
| 7 | The host adapter's base inserts (two, 40 mm apart) and the controller case size | The tray holes and the band clamps are sized to them | SSP-DDR-003, P6 and P8 |
| 8 | The panel's mounting hole positions on its frame | The stand's rail holes are drilled to match | SSP-DDR-003, P12 |
| 9 | The pack moves from legacy discharge (state 5) to heartbeat discharge (mode 2) without opening its output | The bike relies on it if the adapter is slow to start; raised with SwapCell | SSP-DDR-002, item 18 |
| 10 | A low-cost boost charger with input-voltage tracking gives near-MPPT yield from one 18 V panel | R8 assumes 92 % | SSP-PRC-001, open questions |
| 11 | The value of R11's wet stopping target (proposed 14 m from 20 km/h, 1.5 times the dry target) and the wet friction of the wet-weather blocks (assumed 0.25; maker's data needed) | The wet stop of 11.9 m and the decision to keep the 20 km/h cut-off rest on both; the blocks' USD 6 a pair price is also indicative | SSP-CAL-001 section 10; bom line 15 |

## Value engineering

Value-engineering target: USD 250 for the bike kit (a hypothetical control target, not a limit). Estimated cost of the constructable design: USD 208 for the bike kit (USD 42 under the target). The solar set is costed separately at USD 90, and the SwapCell pack (USD 414) is priced once in the SwapCell project. Main cost drivers and savings worth trying:

- The largest lines are the motor wheel (USD 72), the receiver cradle (USD 33), the controller (USD 25), the harness (USD 15), the host adapter (USD 14) and the handlebar display and brake sensors (USD 14).
- The wet-weather brake blocks (two pairs, USD 12, decided 2026-10-02) are the newest line.
- Making the design constructable added USD 8 to the bike kit (cradle USD 28 to 33, hardware USD 8 to 11) and USD 4 to the solar set (stand USD 10 to 14).
- Savings worth trying: buy the receptacle, draw latch and hinge in batches with other SwapCell vehicle receivers; fold the tray from 2 mm aluminium if the retention and end stop margins still hold; a shared panel and stand at a village hub removes the USD 90 solar set for riders who swap packs there.

## Decisions made

| Date | Decision | Decided by | Record |
| --- | --- | --- | --- |
| 2026-09-25 | 48 V on the SwapCell pack; budget kept at USD 250 with R12 covering the bike kit and the solar set costed separately; geared front hub; pack on the down tube; local lacing; 20 km/h default cut-off; pedal assist and walk assist, no throttle; charge on the bike; SwapCell interface v0.3 items W, C and V; pack priced once in SwapCell | Amish: go with recommendation | SSP-DDR-001, items 1 to 13 |
| 2026-09-25 | Handlebar power switch in the INTERLOCK loop; motor thermistor with a controller derate instead of a cutout; raise the legacy-to-heartbeat transition with SwapCell | Amish: "i accept all your recommendations, go with them across all repos." | SSP-DDR-002, items 16 to 18 |
| 2026-09-30 | Make the design physically buildable while drawing the build plan | Amish: "If you are realising that the design cannot be built as per concept - fix the design assumptions to match and be physically feasible as you draw the illustrations." | SSP-DDR-003 (Draft, open for review: open decision 1) |
| 2026-10-01 | Treat `budget_usd` as a value-engineering target, not a limit | Amish: "the budgets are a hypothethical control target to ensure we are thinking along a value engineering lens" | STANDARDS section 18; this register's Value engineering section |
| 2026-10-02 | Design for construction accepted: the changes P1 to P13 as made (open item 1) | Amish: "i approve your recommendations for all 555 open decisions." | SSP-DDR-003, Table 1 |
| 2026-10-02 | Pack swap: gate and draw latch as modelled (option a) for the prototype, reviewed after the first swap trials (open item 2) | Amish: "i approve your recommendations for all 555 open decisions." | SSP-DDR-003, A1 |
| 2026-10-02 | Panel stand in timber (option a) (open item 3) | Amish: "i approve your recommendations for all 555 open decisions." | SSP-DDR-003, A2; review note 2026-09-26, proposal 4 |
| 2026-10-02 | Donor fork slots are never filed for now: donors are chosen whose slots take 10 mm flats, and if the donor survey shows 3/8 in slots are the norm, a motor whose axle flats fit them is looked for first (open item 4) | Amish: "i approve your recommendations for all 555 open decisions." | SSP-DDR-001, item 15 |
| 2026-10-02 | Default region western Kenya and eastern Uganda, where 28 in roadsters and bicycle taxis are common, with a bicycle mechanics' group or rural transport organization there as the partner type; the partner is named when the portfolio picks partners for this area (open item 5) | Amish: "i approve your recommendations for all 555 open decisions." | SSP-DDR-001, item 14 |
| 2026-10-02 | Vertical cranks in the renders accepted (open item 6) | Amish: "i approve your recommendations for all 555 open decisions." | Review note 2026-09-26, proposal 1 |
| 2026-10-02 | Saddle raised about 12 mm in the renders accepted (open item 7) | Amish: "i approve your recommendations for all 555 open decisions." | Review note 2026-09-26, proposal 2 |
| 2026-10-02 | Brake sensors under the bar beside the levers accepted, as `model.py` already has them (SSP-DDR-003, P10) (open item 8) | Amish: "i approve your recommendations for all 555 open decisions." | Review note 2026-09-26, proposal 3 |
| 2026-10-02 | Seated rider kept in the hero render, revisited if it reads oddly (open item 9) | Amish: "i approve your recommendations for all 555 open decisions." | Review note 2026-09-26, proposal 5 |
| 2026-10-02 | Wet braking treated as a safety item: a wet stopping target is added to R11, wet-weather brake blocks suited to steel rims go in the kit, and trials keep a no-wet-riding rule until a wet braking test meets the target (open item 10) | Amish: "i approve your recommendations for all 555 open decisions." | SSP-PRC-001, open questions; SSP-CAL-001 section 10; SSP-REQ-001 R11 |
| 2026-10-02 | Reference motor: a widely sold 250 W front geared hub, such as one of Bafang's; its maker is asked for winding resistance, thermal capacity and gear temperature limit and R3 is rerun; the winding resistance is measured at TRL 4 if the data are not published (open item 11) | Amish: "i approve your recommendations for all 555 open decisions." | SSP-PRC-001, open questions |

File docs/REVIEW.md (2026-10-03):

# Review note: SunSpoke

## Session 2026-09-24: /populate to a strong TRL 2

### What was done

- `docs/01-problem.md` (SSP-PRB-001 v0.2): problem, users (commuters, traders, health workers, mechanics, hub operators), operating environment, constraints, out of scope, prior work without links, open questions; co-design checklist kept.
- `docs/03-requirements.md` (SSP-REQ-001 v0.2): 12 measurable requirements (R1 to R12) with targets, a defined design load case and assumptions.
- `docs/02-concept.md` (SSP-PRC-001 v0.2): how it works, numbered components, energy per km, range, hill climb, solar yield, fork torque and torque arms, cost, design choices, safety, open questions.
- `cad/src/concept_media.py`: massing model of a 28 in roadster (frame from tubes, fork, bars, carrier, wheels) with the kit parts colored and a separate 100 W panel on a stand; 1.75 m scale figure.
- `media/`: hero, blueprint sheet (PNG, PDF, SVG), exploded view with BOM callouts, daily solar energy flow diagram, `model.glb` and `viewer.html`. No cutaway (the inside does not carry the idea).
- `bom/bom.csv`: 14 lines with indicative prices, numbered to match the exploded view; `bom/bom-notes.md` states that the pack is **not** included in the kit cost.
- `README.md`: hero image and links line added.
- `docs/pdf/`: branded PDFs of the three controlled documents.

### Key results (estimates, to be checked at TRL 3)

| Quantity | Estimate | Requirement |
| --- | --- | --- |
| Pack energy, design load case (130 kg, dirt road) | about 12 Wh/km | |
| Range on SwapCell (about 420 Wh usable) | about 35 km loaded, about 60 km light | R2 met |
| Range on alternative 36 V 10 Ah pack | about 27 km loaded | R2 not met |
| Power on 8 % grade at 8 km/h | about 290 W needed, about 330 W available | R3 met on power; motor heating unverified |
| Added mass | about 6.5 kg with pack | R6 met, thin margin |
| One 100 W panel, 4.5 sun hours | about 315 Wh/day stored, about 25 km of loaded riding | R8 met |
| SwapCell recharge 10 to 100 % | about 1.3 days (1.2 to 1.5) | R8 met |
| Torque arm load | about 300 N total at 130 mm, versus about 4 kN on bare dropout faces | R10 by design |
| Kit cost, solar set included, pack excluded | about $261 (bike kit about $175, solar set about $86) | **R12 not met, about 4 % over** |
| SwapCell pack (not in kit cost) | about $370 prototype parts | |

Requirements not met or at risk:

- **R12 (cost) not met:** about $261 against $250.
- **R4 (no fabrication, 90 min fit) at risk:** roadster fork slots may be narrower than the motor's 10 mm axle flats, so fitting may need filing.
- **R11 (stopping distance) unverified:** about 9 m needs about 2.5 m/s² deceleration, which loaded rod brakes may not reach, especially wet.
- **R3 thermal part unverified:** a 250 W geared hub near peak torque on a long climb in 35 °C heat may overheat.
- **R2 would not be met** if the 36 V pack option is chosen.

### Proposed, awaiting Amish

1. **System voltage (pitch-level).** The scaffold assumed 36 V, but SwapCell is 48 V class (about 46.8 V nominal, 54.6 V full). Option A: 48 V motor and controller on SwapCell (meets range, shares packs, keeps pitch; pack about $370, needs a CAN host adapter). Option B: 36 V kit with its own generic pack (cheaper, simpler, misses R2, drops SwapCell). Recommendation: A, with B kept as a later low-cost variant.
2. **Budget.** Options: (a) treat the solar set as optional when a village hub exists, so the bike kit (about $175) meets $250; (b) cut cost (a local-made cradle, cheaper panel) to reach $250; (c) raise `budget_usd` to $300. Recommendation: (a) and redefine R12 as "bike kit $250 or less; solar set costed separately". `project.yaml` is unchanged.
3. Geared front hub motor rather than direct drive, rear hub or mid-drive.
4. Pack in the main triangle on the down tube rather than on the rear carrier.
5. Motor laced locally into a 28 in rim rather than a pre-built wheel.
6. Assist cutoff at 20 km/h by default rather than 25 km/h.
7. Pedal assist plus 6 km/h walk assist; no throttle.
8. Charge on the bike through the cradle, with the host adapter acting as the SwapCell charge host.
9. First partner and region for co-design.

### Safety concerns

- About 468 Wh lithium-ion pack: BMS, fused output, charging in shade on a non-combustible surface, no charging of damaged or wet packs.
- Fork dropout failure from motor reaction torque: torque arms on both sides are mandatory; filed or cracked dropouts must not be converted; fork fatigue is unverified.
- Braking: about 2 to 3 times the kinetic energy of an unassisted loaded roadster, with rod and rim brakes that are weak in the wet.
- Water in connectors causing sudden loss of assist or shorts; front-wheel spin on loose ground with a rear load.

### Problems and notes

- The README "Key components" list still says "36 V 10 Ah pack (SwapCell compatible)", from the scaffold. This session only inserted the hero and links as instructed. Update it once decision 1 is made.
- The SwapCell interface requires a host heartbeat for both discharge and charge, so off-the-shelf controllers and chargers need the host adapter (item 5). Any need to change the SwapCell interface should be raised with that project, not changed here.
- The legacy `cad/src/model.py` placeholder is untouched (TRL 3 work).

### Recommended next step

Review this note and the media, then decide items 1 and 2. If approved, run `/advance-trl3` to check the energy, hill, thermal, braking and fork load estimates by calculation and produce the parametric model and drawing sheet.

## Session 2026-09-25: TRL 3

Authority: on 2026-09-25 Amish wrote "proceed with all of your recommendations across all batches. Make sure we don't proceed to TRL 4 on any of them." He also approved the SwapCell interface v0.3 additions (wake, charge-discharge mode, latch vibration rating) and the rule that shared SwapCell packs are priced once and excluded from each kit budget. TRL 4 is on hold by his instruction.

### What was done

- `docs/decisions/0001-trl2-review-decisions.md` (SSP-DDR-001 v0.1): decided and open items (below).
- `docs/04-calcs/01-sizing.md` (SSP-CAL-001 v0.1) with `docs/04-calcs/sizing.py` and `docs/04-calcs/results.csv`: mass, energy and range, hill and motor heating, solar, SwapCell items W, C and V, torque arms, cradle retention, pack fit, braking, cost, and a status for every requirement.
- `cad/src/model.py`: parametric build123d model (donor roadster, motor, torque arms, SwapCell envelope, cradle with V1 lever and receptacle, host adapter, controller, solar set) with fit checks; exports `cad/step/` and `cad/stl/` (`sunspoke-kit`, `sunspoke-cradle-with-pack`, `sunspoke-assembly`).
- `cad/src/sheets.py` and `cad/drawings/SSP-DWG-001` (SVG, PDF, PNG): general arrangement at Rev P1 with a 1:5 cradle detail, "PRELIMINARY, NOT FOR FABRICATION". SSP-DWG-001 was free (the concept sheet is SSP-DWG-010).
- `bom/bom.csv` and `bom/bom-notes.md`: every line priced with a supplier type; cradle $22 to $28 (V1 lever, coding resistor), host adapter $12 to $14 (charge inlet); pack $414 from SWC-CAL-001, excluded.
- `docs/01-problem.md`, `docs/02-concept.md`, `docs/03-requirements.md` moved to v0.3 (decisions, corrected numbers, new R13, R1 and R12 redefined, status column).
- `cad/src/concept_media.py` now draws from the model; all media refreshed and checked (flow labels shortened to stop overlap; exploded callouts moved apart). Temporary `media/_views*` folders deleted.
- `project.yaml`: `trl: 3`, `trl_target: 3`, evidence listed; `budget_usd` unchanged at 250. `README.md`: TRL 3 badge, budget line, drawing and calc links, key components. The README no longer had a literal "36 V 10 Ah" line (it read "48 V SwapCell pack (proposed, see precis)"); it now states 48 V as decided.
- Citations: two sources checked with web search on 2026-09-25 and added to SSP-PRB-001 (World Bicycle Relief "The Bike" page; Wikipedia "Pedelec" for Regulation (EU) No 168/2013, a secondary source). The other prior-work entries remain unsourced general descriptions and are flagged as unverified.

### Requirements (SSP-CAL-001)

| ID | Status | Value |
| --- | --- | --- |
| (none) | **Not met** | No requirement is shown to be not met |
| R3 | At risk | Motor winding about 100 °C at the top of the 500 m climb from 35 °C (base), about 139 °C in a hotter-motor case; 204 W and 32.5 N·m needed |
| R4 | At risk | 10 mm axle flats may need about 0.24 mm filed per side from 9.53 mm roadster slots |
| R11 | At risk | 8.5 m dry from 20 km/h (9 % margin); 21.7 m wet |
| R7, R9, R10, R13 | Not verifiable at TRL 3 | Sealing, swap time, cut-off timing, V1 retention (rotation margin 1.40 at 25 g) |
| R1, R5 | Met (specification, on paper) | 250 W, 20 km/h default, walk assist; pack fits the triangle with 164 mm removal travel |
| R2 | Met | 37 km design case (23 km with 80 kg cargo) |
| R6 | Met | 6.65 kg |
| R8 | Met | 27 km/day; 1.3 days to recharge |
| R12 | Met (redefined) | Bike kit $183; solar set $86 separately; pack $414 in SwapCell |

The model check found that the TRL 2 pack position (52 % up the down tube) left only 135 mm of removal travel against 143 mm needed; the pack now sits at 48 %.

### Decisions recorded (Decided by Amish, 2026-09-25: go with recommendation)

48 V on SwapCell (Option A; 36 V only as a later variant); budget kept at $250 with R12 redefined to the bike kit and the solar set costed separately; geared front hub; pack on the down tube; local lacing; 20 km/h default cut-off; pedal assist plus walk assist, no throttle; charge on the bike with the host adapter as charge host; SwapCell interface v0.3 items W, C and V; SwapCell pack priced once and excluded.

### Still awaiting Amish (items 3 to 5 decided later the same day, see the next session)

1. First co-design partner and region (no recommendation; picked per area later).
2. Whether light slot filing is acceptable with torque arms (R4; no recommendation until the donor survey).
3. Handlebar power switch in series with the INTERLOCK coding resistor, host adapter powered from legacy discharge or the charge inlet. Decided by Amish, 2026-09-25: go with recommendation (SSP-DDR-002).
4. Controller with a motor thermistor input so R3 becomes a derate, not a cutout. Decided by Amish, 2026-09-25: go with recommendation (SSP-DDR-002).
5. Decided by Amish, 2026-09-25: go with recommendation (raise with SwapCell; cross-repo action, SSP-DDR-002). For the SwapCell project, not changed here: interface v0.3 should state that a pack in legacy discharge (state 5) moves to heartbeat discharge (mode 2) without opening the output.

### Safety concerns

- Wet braking: about 22 m from 20 km/h with rod brakes on steel rims, versus 8.5 m dry. R11 covers only dry roads; a wet target and better blocks should be considered.
- Motor overheating on long loaded climbs in heat; a cutout on a hill can stall a loaded bike.
- Pack retention: V1 lever and clamp torque are safety-critical; rotation margin at 25 g is only about 1.4 on paper.
- Fork dropouts: torque arms mandatory; filed or cracked dropouts must not be converted; fork fatigue unverified.
- 468 Wh lithium-ion pack: charge in shade on a non-combustible surface; no damaged or wet packs.

### TRL 4 material

None found. `build-log/` holds only its README; `electronics/` and `firmware/` are empty. Nothing beyond TRL 3 was created.

### Recommended next step

Amish reviews SSP-DDR-001 open items 1 to 4 and forwards item 5 to the SwapCell project. Paper work that stays within TRL 3: pick a named 250 W geared hub and controller and rerun R3 with datasheet values, and define the donor survey questions (slot width, down tube diameter, frame size) with the partner once chosen.

TRL 4 is on hold by Amish's instruction. For the record only, TRL 4 would need: a bench-built kit on a donor roadster, a lab test report (TST, `environment: lab`) covering motor temperature on a loaded climb profile, brake cut-off timing, stopping distance dry and wet, cradle vibration and shock to latch class V1, and IP checks, plus build log entries.

## Session 2026-09-25: recommendations accepted

Authority: on 2026-09-25 Amish wrote "i accept all your recommendations, go with them across all repos." Every open item with a recommendation is now "Decided by Amish, 2026-09-25: go with recommendation", recorded in `docs/decisions/0002-recommendations-accepted.md` (SSP-DDR-002 v0.1). Items without a recommendation stay open. TRL stays at 3.

### Decisions applied and what changed

| Item (SSP-DDR-001) | Decision | Change, before and after |
| --- | --- | --- |
| 16, power switch in the INTERLOCK loop | Adopt | R10 now requires the switch; already costed in BOM item 8 and shown on the drawing, so no cost or geometry change |
| 17, motor thermistor and controller derate | Adopt | BOM item 1 $70 to $72, item 3 $22 to $25; bike kit $183 to $188 (margin $67 to $62); generic share 84 % to 85 %. R3 restated: derate from 110 °C, winding at or below 120 °C, no abrupt cutout. New CAL result: derate starts after 697 m of the 8 % climb (base case, so the 500 m design climb runs at full assist) or 225 m (hot case); sustained 4.7 or 3.7 km/h on an unending climb |
| 18, legacy-to-heartbeat transition | Raise with SwapCell | Cross-repo action below; nothing changed here |

`budget_usd` stays at $250 (the budget decision of SSP-DDR-001 already redefined R12 to the bike kit). Documents changed: SSP-REQ-001 v0.3 to v0.4, SSP-PRC-001 v0.3 to v0.4, SSP-CAL-001 v0.1 to v0.2, SSP-DDR-001 v0.1 to v0.2, SSP-DWG-001 Rev P1 to P2 (notes only; geometry unchanged), new SSP-DDR-002 v0.1. `bom/bom.csv`, `bom/bom-notes.md`, `docs/04-calcs/sizing.py` and `results.csv`, `cad/src/sheets.py` and `concept_media.py` (blueprint cost) updated; STEP, STL, drawings, media and PDFs regenerated.

Other work this session: all generated files re-rendered so the footer reads designmolecule.com; README gains "Concept rationale", "Burning platform", "Where it could be used" and "What sparked the idea" (the 1895 Bolton hub-motor bicycle patent, US 552,271).

### Requirement status (SSP-CAL-001 v0.2)

| Status | Requirements |
| --- | --- |
| Not met | None |
| At risk | R3 (100 °C base, 139 °C hot case; hot case now derates after 225 m instead of cutting out), R4 (slot filing about 0.24 mm per side), R11 (8.5 m dry, 21.7 m wet) |
| Not verifiable at TRL 3 | R7, R9 (85 % generic), R10, R13 |
| Met | R1, R2 (37 km), R5, R6 (6.65 kg), R8 (27 km/day, 1.3 days), R12 (bike kit $188) |

### Still awaiting Amish

1. First co-design partner and region (no recommendation).
2. Whether light slot filing is acceptable with torque arms (R4; no recommendation until the donor survey).

### Cross-repo actions

- **SwapCell:** interface v0.3 should state that a pack in legacy discharge (state 5) moves to heartbeat discharge (mode 2) without opening the output (SSP-DDR-001 item 18, decided). Not changed here.

### TRL 4

TRL 4 remains on hold by Amish's instruction. Choosing and calibrating a real thermistor derate curve and a hill test are TRL 4 work and were not started. `trl: 3`, `trl_target: 3`.

## Session 2026-09-26: sources strengthened

README "Where it could be used" country table, per Amish's instruction of 2026-09-26 ("Fix the weaker sources"). Every link below was fetched and checked against the claim it supports.

| Row | Old source | New source |
| --- | --- | --- |
| Uganda and Kenya | Wikipedia, "Boda boda" (alone) | *Daily Monitor* (Uganda), May 25, 2017; row now states only the Busia "border, border" origin it reports (the "1980s" date is dropped) |
| Malawi, Tanzania and Zambia | World Bank 2025 press release, which names no countries | Row renamed "Wider sub-Saharan Africa"; same World Bank source, now matching what it says |
| India and Bangladesh | None | Replaced by "India": TERI, *Benefits of Cycling in India* (2020), reporting Census of India bicycle ownership and rural work-trip share |
| Andean and Central American highlands | None | Replaced by "Haiti": World Bank press release, October 18, 2024 (access about 47.1 percent in 2021; solar mini-grid financing) |
| Netherlands | DutchNews.nl (alone) | BOVAG and RAI Vereniging press release, February 26, 2024 (804,000 bicycles, about 56 percent e-bikes); DutchNews.nl kept alongside |

"What sparked the idea" already rests on the primary patent record (Google Patents, US552271A); rechecked, unchanged. No controlled document changed. Still open: `docs/01-problem.md` prior-work line on pedelec rules cites Wikipedia alone; it is outside this session's scope and should cite Regulation (EU) No 168/2013 on EUR-Lex at the next revision.

## Session 2026-09-26: product appearance model and photoreal renders

Amish chose this repo for the first batch of product renders on 2026-09-26. This session adds `cad/src/product_model.py`, an appearance model for photoreal renders, and points the README hero at `media/render-hero.png` (with an exploded render link); the render files are produced separately.

### What product_model.py adds

- `product_parts()`: 96 parts (66 shell, 15 internal, 14 accessory, 1 context), each with colour, material class, BOM line and explode offset. All main dimensions and interfaces come from `PARAMS`, `geometry()`, `cradle_location()`, `pack_local()` and `receptacle_local()` in `model.py`.
- Donor roadster, shown as part of the product: lugged black enamel frame, fork, chrome stem and swept bars with ribbed grips and brake levers, sprung leather saddle, tube carrier, chainring, chain and block pedals, and 36-spoke wheels.
- Item 1: brushed hub motor with ribbed drum, spoke flanges, side covers and screws, a teal band, rating label, keyed axle, axle nuts and the cable exit, laced into the front rim.
- Item 2: keyed torque arms with band clips and bolts on both fork blades.
- Items 4 and 6: the cradle with guides, end stop and receptacle; the teal V1 preload lever with grip and pivot pin; stainless band clamps with rubber liners and screws; and the SwapCell pack with dark end caps, carry handle, accent stripe, label and a four-segment charge gauge (three segments lit).
- Item 5: potted host adapter with a parting line, the keyed charge inlet, a lit status light and a label.
- Item 3: finned aluminium controller with sealed end caps, glands, a name plate and straps to the seat tube.
- Items 7 to 9: magnet disc and Hall sensor; handlebar display with lit assist and charge segments, power switch, walk-assist button and two brake-lever sensors; harness with cable ties and a sealed fuse holder behind a clear cover.
- Items 10 to 13: panel with aluminium frame, 24 cells, busbars and junction box; timber A-frame stand with coach bolts; finned boost charger with a lit charge light; panel lead; and the 5 m charge cable with its plug in the charge inlet.
- Context: the shared clay mannequin (1.75 m) in the "ride" pose, placed on the bike's bottom bracket, with the torso and arm angles set so the hands close on the grips and the feet land on the pedals.
- `TITLE` and three `RENDER_VIEWS`: "hero" (front right, about 18 deg elevation, rider and solar set), "exploded" (front right, about 28 deg), and "detail" (front right, about 12 deg: the hub motor wheel, fork and torque arms without the rider).

### Where the appearance model differs from model.py

Each is render-only; `model.py`, the STEP files and SSP-DWG-001 are unchanged.

1. **Cranks turned to vertical** so the rider's feet sit on the pedals (cranks rotate; no dimension changes). Proposed, awaiting Amish. Recommendation: accept.
2. **Saddle top raised about 12 mm** (to about 964 mm) to meet the mannequin's seat point. Proposed, awaiting Amish. Recommendation: accept; it is within normal saddle-height adjustment.
3. **Brake cut-off sensors moved about 45 mm forward and 32 mm lower** (to X = 905 mm, Z = 918 mm, under the bar at the lever pivots) so the rider's hands clear them; `model.py` places them on the grip section. Proposed, awaiting Amish. Recommendation: move the envelopes in `model.py` to match at the next drawing revision.
4. **Panel stand drawn as square timber** (36 mm legs, 28 x 24 mm rails) instead of round tube, plus a small upright for the charger, which floats in `model.py`. The BOM allows steel angle or timber. Proposed, awaiting Amish. Recommendation: accept, and add the charger upright to `model.py` at the next revision.
5. **Hero scene shows the rider seated while the pack charges** from the panel (the adapter's mode 4, bike on while charging). This reads as a waiting rider rather than riding. Proposed, awaiting Amish. Options: keep it; or pose a standing owner beside the parked bike. Recommendation: keep it for one image that shows the whole system; revisit if the render reads oddly.

### TRL

This is an appearance model only: no tolerances, fabrication detail or build instructions were added. `trl: 3` and `trl_target: 3` are unchanged, and TRL 4 remains on hold by Amish's instruction.

## Session 2026-09-27: kit 1.5.0 and image quality

- Kit 1.5.0 synced: STANDARDS v1.5 (sections 12 to 15: product renders, storefront images and image quality, public release, authorship and signing), `.kit/cards.py`, `.kit/image_qc.py`, `.kit/release_gate.py`, issue templates, and the `/render-product` and `/release` commands. `CLAUDE.md` now matches `.kit/CLAUDE.md`.
- Every `media/render-*.png` recaptioned from its original render with the new layout: the title, concept label and repository sit in a band above the render and the view note in a band below it, each line wrapped to the image width, so no text overlaps other text or the render or runs off the image. `media/card.png` and `media/social-preview.png` regenerated with the same rules.
- `python .kit/image_qc.py` and `python .kit/release_gate.py` pass. trl stays 3.

## Session 2026-10-01: kit 1.7.0, design made constructable, build plan

Authority: Amish's instruction of 2026-09-30 to give every repo the approved build plan and to "fix the design assumptions to match and be physically feasible as you draw the illustrations", with open decisions in a separate register (SSP-DEC-001), and his 2026-10-01 guidance that `budget_usd` is a value-engineering target. Kit 1.7.0 installed (`.kit/`, `.claude/commands/`, `CLAUDE.md`).

### Design changes made for construction (SSP-DDR-003, Draft, open for Amish's review)

1. Cradle base: the concept's flat plate cut into the down tube; now a folded 3 mm 5052 aluminium tray on three 120 degree aluminium V-saddles with rubber liners (aluminium, not steel, to hold the cradle at 1.10 kg).
2. Band clamps: drawn as rings through the plate; now three band clamps (was two), each through two slots in the tray, round the saddle and under the tube. The real band path wraps about 150 degrees of the tube, so a third band was needed to keep the 25 g rotation margin (1.44, was 1.40).
3. End stop: a solid block with the receptacle inside it; now a folded aluminium end stop with an open-topped plug notch, bolted to the tray and guides, the receptacle bolted behind it.
4. V1 lever: three loose blocks whose hinge stood in the pack's path, so the pack could not come out; now a drop-down gate with a rubber pad on a butt hinge, closed by an over-centre draw latch with a safety catch (330 N preload, latch pull about 314 N).
5. Slide rails and catch: loose steel bars; now HDPE slide strips and a steel catch bar on screws from below.
6. Host adapter: floating beyond the base; now on a 70 mm extension of the tray with a lead to the receptacle.
7. Torque arms: ran into the fork blades, clips not joined; now joggled 20 x 5 mm steel arms with an open 10 mm slot on the axle flats, held by a band clamp round blade and arm. Donor dropouts and a 150 mm axle added to the model.
8. Controller: floating; now on a rubber pad with two band clamps round the seat tube.
9. Pedal-assist sensor: disc on nothing, no sensor; now a disc clamped on the spindle and a Hall sensor on a bracket under the left lockring.
10. Display and brake sensors: cut into the bar; now each on its own bar clamp, magnets on the levers (matches proposal 3 of 2026-09-26).
11. Harness: through open space and the cradle; now routed along the left side of the tubes.
12. Panel stand: legs ran into the panel, nothing held it; now a bolted timber A-frame, panel bolted to its rails, charger on the rear leg.
13. Front wheel spokes now run from the motor's flanges (context).

`cad/src/model.py` now runs 57 constructability checks (`--check`), including the pack's removal path; all pass.

### Key results (SSP-CAL-001 v0.3)

| Quantity | Before | Now |
| --- | --- | --- |
| Added mass with pack (R6, 7 kg) | 6.65 kg | 6.78 kg (0.22 kg margin) |
| Retention at 25 g: axial / rotation margin | 6.8 / 1.40 | 7.7 / 1.44 |
| End stop at 25 g | (solid block) | about 62 MPa, factor 3.1 on yield |
| Pack clearance in the triangle; free travel | 123 mm; 164 mm | 121 mm; 165 mm (143 needed), path checked |
| Bike kit cost (value-engineering target USD 250) | USD 188 | USD 196, USD 54 under the target |
| Solar set cost | USD 86 | USD 90 |

No requirement changed status: none not met; R3, R4 and R11 at risk; R7, R9, R10 and R13 not verifiable at TRL 3.

### Files

- New: `docs/05-build-plan.md` (SSP-BLD-001 v0.1), `docs/06-design-decisions.md` (SSP-DEC-001 v0.1), `docs/decisions/0003-design-for-construction.md` (SSP-DDR-003 v0.1), `cad/src/build_plan_media.py`, `cad/drawings/SSP-DWG-101` to `110`, `docs/05-build-plan/` (3 overviews, tray layout, wiring, 10 joints, 15 steps).
- Updated: `cad/src/model.py`, `cad/src/sheets.py` (SSP-DWG-001 Rev P3), `cad/src/concept_media.py`, `cad/step/`, `cad/stl/`, `media/` concept media and `model.glb`, `bom/bom.csv` (lines 2, 4, 7, 8, 12, 14), `bom/bom-notes.md`, `docs/04-calcs/sizing.py` and `results.csv`, SSP-CAL-001 v0.3, SSP-REQ-001 v0.5, SSP-PRC-001 v0.5, `project.yaml` (`design_state: constructable`, new evidence), `README.md`.

### Proposed, awaiting Amish

All in the design decisions register: accept SSP-DDR-003 (decision 1); the two-movement pack swap (2); timber stand (3); plus the open items carried over (fork slot filing, co-design partner, appearance-model proposals 1, 2, 3 and 5 of 2026-09-26, wet braking, motor data).

### Stale media (made on Amish's Mac)

The design changed visibly at the cradle, lever, torque arms and panel stand, so `media/render-hero.png`, `media/render-exploded.png`, `media/render-detail.png`, `media/card.png`, `media/social-preview.png` and the appearance model `cad/src/product_model.py` are stale and need regenerating on the Mac. They were not regenerated here.

### Safety

Unchanged hazards (lithium pack, retention, fork dropouts, wet braking, motor heat). The build plan adds seven safety stops (S1 to S7); first rides are TRL 4 tests on a closed, dry site. Retention depends on the three band clamps being at torque and the latch's safety catch being on.

### Recommended next step

Amish reviews SSP-DDR-003 and the register. TRL 4 (building to the plan) remains on hold; trl stays 3.

## Session 2026-10-02: open decisions decided

Amish approved every recommendation for the open decisions on 2026-10-02: "i approve your recommendations for all 555 open decisions."

### Decisions recorded

Eleven, all moved to "Decisions made" in SSP-DEC-001 (open items 1 to 11): design for construction accepted (SSP-DDR-003, P1 to P13); gate and draw latch for the pack swap; timber panel stand; the fork is never filed for now, and donors are chosen whose slots take 10 mm flats; western Kenya and eastern Uganda as the default region, with a bicycle mechanics' group or rural transport organization as the partner type; vertical cranks, the raised saddle, brake sensors under the bar and the seated rider accepted in the renders; R11 gains a wet stopping target, wet-weather brake blocks go in the kit and trials are not ridden in the wet until a wet braking test meets the target; a widely sold 250 W front geared hub such as one of Bafang's as the reference motor for rerunning R3.

### Documents changed

- `docs/06-design-decisions.md` SSP-DEC-001 v0.2: decisions made; open decisions section now reads "None"; To confirm items 1 and 2 updated for the no-filing rule.
- `docs/decisions/0003-design-for-construction.md` SSP-DDR-003 v0.2: accepted (status Draft kept); A1 and A2 as recommended.
- `docs/03-requirements.md` SSP-REQ-001 v0.6: R11 adds a wet stopping target; safety note.
- `docs/04-calcs/01-sizing.md` SSP-CAL-001 v0.4: R4, R11 and motor assumption text; no figures changed.
- `docs/02-concept.md` SSP-PRC-001 v0.6 and `docs/01-problem.md` SSP-PRB-001 v0.4: region and partner type, slot filing, reference motor and wet braking.
- `docs/05-build-plan.md` SSP-BLD-001 v0.2: safety stop S7 adds the no-wet-riding rule.
- `README.md`: Safety note adds the no-filing rule, the wet-weather blocks and the no-wet-riding rule.
- `bom/bom-notes.md`: wet-weather brake blocks and the reference motor noted.

### Follow-up actions to carry approved decisions into the design

1. Decision 10 (calculations): set the value of R11's wet stopping target and calculate the wet stopping distance with wet-weather blocks suited to steel rims; revisit the 20 km/h default cut-off once the wet target is set.
2. Decision 10 (BOM): add wet-weather brake blocks for steel rims, front and rear, as a line in `bom/bom.csv`.
3. Decision 10 (pictures): add fitting the wet-weather blocks to the build plan (section 1 and the brake check) with its picture.
4. Decision 11 (calculations): rerun R3 with the reference motor's winding resistance, thermal capacity and gear temperature limit once the maker supplies them.
5. Decision 4 (BOM): after the donor survey, confirm the motor's axle flats fit the common slot width (line 1).

### Points found in the review

- Items 3 and 8 are already settled by DDR-003 (P12 makes the stand timber; P10 moves the brake sensors), so accepting item 1 closes them.
- R11 is specified dry only, yet the calculation note itself calls the 21.7 m wet stop "a safety concern whatever the requirement says"; the register should treat item 10 as a safety item, not an option.
- The 20 km/h default cut-off was decided partly on the dry braking result; it should be revisited once the wet target is set.

## 2026-10-02: Approved follow-ups carried out

Amish approved on 2026-10-02 that the follow-up actions listed above be carried out. Three of the five are done; two are not.

### Done

1. **Decision 10, calculations.** `docs/04-calcs/sizing.py` now takes a proposed wet target of 14 m from 20 km/h (1.5 times the dry target) and assumes a wet friction of 0.25 for the wet-weather blocks. Wet stop with those blocks: 11.9 m (deceleration 1.69 m/s2; 1.38 needed; margin 23 %). Standard blocks wet: 21.8 m. The highest speed that meets 14 m wet is 21.9 km/h, so the 20 km/h default cut-off is kept; at 17.1 km/h the wet stop would match the dry 9 m figure. Dry stop 8.5 m (9 % margin) is unchanged.
2. **Decision 10, BOM.** Line 15 added to `bom/bom.csv`: wet-weather brake blocks, two pairs at USD 6 (USD 12; an indicative price, not a quote). Bike kit USD 208 against the USD 250 target (USD 42 under); solar set USD 90 unchanged. Added mass 6.88 kg (R6 margin 0.12 kg).
3. **Decision 10, pictures and model.** `cad/src/model.py` has four blocks on the rims (59 of 59 constructability checks pass; STEP and STL regenerated). Build plan: new step 11, new Figure 26 (joint 11) and section 3.9.6, overview item 10, steps 11 to 15 renumbered 12 to 16, new first check. General arrangement DWG-001 Rev P4 and the concept media (DWG-010 Rev P3) regenerated. `cad/src/product_model.py` has the blocks, with sizes from `model.py`.

### Not done

4. Decision 11 (R3 rerun with the reference motor's data): needs the maker's winding resistance, thermal capacity and temperature limit; outreach is Amish's.
5. Decision 4 (confirm the motor's axle flats): needs the physical donor survey.

### Documents changed

- `docs/04-calcs/01-sizing.md` SSP-CAL-001 v0.5; `docs/03-requirements.md` SSP-REQ-001 v0.7; `docs/02-concept.md` SSP-PRC-001 v0.7; `docs/06-design-decisions.md` SSP-DEC-001 v0.3 (To confirm item 11, Value engineering section: "Value-engineering target: USD 250 ... Estimated cost of the constructable design: USD 208 for the bike kit (USD 42 under the target)"); `docs/05-build-plan.md` SSP-BLD-001 v0.3; `README.md`; `bom/bom.csv`, `bom/bom-notes.md`.

### Requirement status changes

None. R11 stays at risk: the wet stop with the new blocks rests on an assumed friction. R6 still met (6.88 kg), R12 still met (USD 208).

### Proposed, awaiting Amish

- The value of R11's wet target: 14 m from 20 km/h (alternatives: 9 m, the dry figure, which would need a cut-off near 17 km/h; or a value from the blocks maker's data). Recommended: 14 m.
- The assumed wet friction of 0.25 for the blocks, and their USD 6 a pair price: both unverified until the maker's data or a wet braking test (TRL 4, on hold).
- The blocks are drawn as plain rubber blocks on the rim faces; the donor's stirrups and rods are not drawn (appearance and model simplification).

### Cross-repo actions

None for SwapCell or any other repo.

### Safety

Wet braking remains the main hazard. The 20 km/h cut-off, the brake cut-off sensors and the no-wet-riding rule (build plan S7) stay; no trial is ridden in the wet until a wet braking test meets the target.

### Next step

Amish confirms the wet target and friction assumption and the render on the Mac. TRL 4 stays on hold.

## 2026-10-02: photoreal renders redone on the constructable design

Rendered with Blender Cycles on Amish's Mac from the updated appearance model; captioned with `.kit/photo_caption.py`; `media/card.png` and `media/social-preview.png` regenerated with `.kit/cards.py`. Views: hero, exploded, detail. image_qc passes. Appearance deviations are those logged above as proposed, awaiting Amish.

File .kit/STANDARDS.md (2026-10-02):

---
doc_id: OHP-STD-001
title: Documentation and drawing standard
project: Open Hardware Portfolio
doc_type: Standard
version: "1.7"
status: Released
date: 2026-09-30
author: Amish Chadha
license: CC-BY-SA-4.0
revisions:
  - version: "1.0"
    date: 2026-09-24
    author: Amish Chadha
    change: First release of the standard
  - version: "1.1"
    date: 2026-09-24
    author: Amish Chadha
    change: Adopt Technology Readiness Levels (section 9) for project maturity
  - version: "1.2"
    date: 2026-09-24
    author: Amish Chadha
    change: Portfolio phase cap (section 10), concept media standard (section 11), CLAUDE.md guardrails
  - version: "1.3"
    date: 2026-09-24
    author: Amish Chadha
    change: Scale figure, interactive 3D viewer and flow diagrams added to concept media; session slash commands
  - version: "1.4"
    date: 2026-09-26
    author: Amish Chadha
    change: Every sheet and render names the project and its GitHub repository; overall dimensions, ISO centre lines and 300 dpi PNG on sheets; titles name the device and view labels state the viewing direction; optional photoreal renders with Blender
  - version: "1.5"
    date: 2026-09-27
    author: Amish Chadha
    change: Product renders (section 12), storefront images and image quality check (section 13), public release and release gate (section 14), authorship, citation and commit signing (section 15)
  - version: "1.6"
    date: 2026-09-29
    author: Amish Chadha
    change: Licensing metadata with REUSE (section 16), Zenodo DOI and Software Heritage archiving (section 17), release gate checks REUSE and a single CITATION.cff license, archive.py
  - version: "1.7"
    date: 2026-09-30
    author: Amish Chadha
    change: Concept and constructable design states; design decisions register (DEC) kept apart from the build plan; prototype build plan (BLD, section 18) with pictures by component is required TRL 3 evidence; every repo targets TRL 3 during the populate phase; build_views.py; /to-trl3 and /build-plan commands
---

# Documentation and drawing standard

Every project in the portfolio uses this standard, so that each precis, write-up and sketch looks the same and carries its own version history. The standard ships as a kit in each repo's `.kit/` folder. The kit version is in `.kit/KIT_VERSION`.

## 1. Document types and IDs

Every controlled document has a unique ID in the form `PRJ-TYP-NNN`.

- `PRJ` is the three-letter project code listed in section 7.
- `TYP` is the document type code from the table below.
- `NNN` is a sequence number within that project and type, starting at 001.

| Code | Type | Typical file |
| --- | --- | --- |
| PRC | Design precis | `docs/02-concept.md` |
| PRB | Problem statement | `docs/01-problem.md` |
| REQ | Requirements | `docs/03-requirements.md` |
| CAL | Calculation or sizing note | `docs/04-calcs/*.md` |
| DDR | Design decision record | `docs/decisions/*.md` |
| BOM | Bill of materials | `bom/bom.csv` |
| DWG | Drawing or sketch sheet | `cad/drawings/*.svg` |
| BLD | Prototype build plan (section 18) | `docs/05-build-plan.md` |
| DEC | Design decisions register (section 18) | `docs/06-design-decisions.md` |
| TST | Test plan or test report (front matter adds `environment: lab` or `relevant`) | `docs/05-tests/*.md` |

Example: `TBK-PRC-001` is the ThermaBrick design precis.

## 2. Revision scheme

| Artifact | While in draft | When released | Change after release |
| --- | --- | --- | --- |
| Documents | 0.1, 0.2, 0.3 ... | 1.0 | 1.1 for minor edits, 2.0 for a design change |
| Drawings | Rev P1, P2 ... (preliminary) | Rev A | Rev B, C ... |

- Every change to a controlled document adds a row to its revision history before the commit.
- The `version` field in front matter always equals the newest row in `revisions`. The renderer rejects a document where they differ.
- Status is one of `Draft`, `In review`, `Released` or `Superseded`. Draft and In review documents print with a status band on every page.
- Every release is tagged in Git as `<doc_id>/v<version>`, for example `TBK-PRC-001/v1.0`. Drawings are tagged `TBK-DWG-001/revA`.
- Git history is the full audit trail. The in-document revision table is the human-readable summary.

## 3. Document front matter

Every Markdown document under version control starts with this block:

```yaml
---
doc_id: TBK-PRC-001
title: ThermaBrick design precis
project: ThermaBrick
doc_type: Precis
version: "0.1"
status: Draft
date: 2026-09-24
author: Amish Chadha
license: CERN-OHL-S-2.0
revisions:
  - version: "0.1"
    date: 2026-09-24
    author: Amish Chadha
    change: Initial draft
---
```

Quote version numbers so YAML keeps `1.0` as text instead of turning it into a number. List revisions newest last.

## 4. Writing style

- Chicago Manual of Style.
- No em dashes. Restructure the sentence instead.
- Lead each section with its conclusion, then support it.
- SI units throughout, in the form `12 kW`, `450 °C`, `3.2 m`. Imperial values may follow in parentheses.
- Number every figure and table ("Figure 2", "Table 1") and give each a caption.
- State every assumption in the calculation that depends on it.
- Put safety notes in a blockquote starting with **Safety:**.

## 5. Visual identity

| Element | Specification |
| --- | --- |
| Typeface | IBM Plex Sans for text, IBM Plex Mono for code and values (SIL Open Font License, bundled in `.kit/fonts`) |
| Ink | `#111827` |
| Secondary text | `#4B5563` |
| Rules and grid | `#D1D5DB` |
| Accent (one only) | `#0F766E` teal |
| Document page | US Letter, 20 mm margins |
| Drawing sheet | ANSI B landscape (431.8 x 279.4 mm) |
| Footer | Document ID, version, status, license and designmolecule.com on every page |

## 6. Drawing and sketch conventions

- Units are millimeters unless the title block says otherwise.
- Third-angle projection, marked with the symbol in the title block.
- Line weights: visible outlines 0.5 mm, hidden lines 0.25 mm dashed, center lines 0.18 mm chain.
- The title block contains the project, title, drawing number, revision, scale, units, projection, sheet, author, date, material or notes, and license.
- Every sheet and every render names the project and its GitHub repository (from `repo:` in `project.yaml`), at the top of the sheet and in the title block, so a printed or forwarded sheet is never anonymous.
- The drawing title names the device, not only the drawing type (for example "Handheld near-infrared resin scanner: general arrangement").
- Every view label states its scale and viewing direction (for example "Scale 1:1; side elevation looking along +Y"), and every isometric or render states where it is seen from.
- Orthographic views generated with `add_ortho` carry overall dimensions (length and depth on the top view, height on the front view) and ISO 128 centre lines on cylinders; hidden lines are dashed. Tolerances are not shown before TRL 4.
- Sheets are exported as SVG, PDF and a 300 dpi PNG.
- The revision table in the top right of the sheet lists every revision.
- Concept sketches use the same sheet and title block and carry the label "CONCEPT, NOT FOR FABRICATION".
- Geometry comes from `cad/src/*.py` (build123d). Sheets are generated by `.kit/drawing.py` and never edited by hand.

## 7. Project codes

| Code | Project | Code | Project | Code | Project |
| --- | --- | --- | --- | --- | --- |
| TBK | ThermaBrick | PCF | PicoFlow | HLT | HelioLite |
| CCB | CharCube | DRN | DustRunner | TRT | TremorTrace |
| STC | StepCue | FXH | FlexHand | CPD | ColdPod |
| SCL | SunClave | STR | SteamRoot | GGD | GrainGuard |
| SDL | SeedLine | ZBX | ZeerBox | RMS | RootMesh |
| DWD | DewDrive | SSK | StillStack | PPR | PotPress |
| WWT | WaterWatch | LMF | LumaFlow | FCL | FieldCell |
| CNP | ConePro | CVC | CulvertCrawl | EGD | EmberGuard |
| SNF | SnapFrame | CGM | CargoMule | SCM | StepClimber |
| SWC | SwapCell | PLP | PalletPilot | FTK | FlatTrike |
| WWK | WaterWalker | GRR | GrowRider | SSP | SunSpoke |
| SGN | StepGen | PBX | PowerBox | WML | WasteWise-ml |
| WSC | WasteWise Scan | RFE | ReflowEconomy | | |
| OHP | Portfolio-wide | | | | |

## 8. Build and publish

- `python .kit/render.py` checks every controlled document and renders it to `docs/pdf/<doc_id>_v<version>.pdf`.
- `python .kit/drawing.py` (called from each project's `cad/src/sheets.py`) builds drawing sheets as SVG and PDF in `cad/drawings/`.
- The GitHub Action in `.github/workflows/docs.yml` runs the checks on every push and attaches PDFs to a GitHub Release whenever a release tag is pushed.
- Public releases follow section 14: `python .kit/release_gate.py` must pass, and the release tag is `v0.<TRL>.0` (for example `v0.3.0` at TRL 3).

## 9. Technology Readiness Level (TRL)

Each project states its maturity as a Technology Readiness Level on the NASA and US DOE 1 to 9 scale. The TRL rates this specific design, not the underlying technology. A sand battery is commercial elsewhere, but a new sand battery design starts at TRL 2 until evidence shows otherwise.

| TRL | Definition | Evidence the repo must contain |
| --- | --- | --- |
| 1 | Basic principles observed | Problem statement (PRB) |
| 2 | Technology concept formulated | Draft precis (PRC) and requirements (REQ) |
| 3 | Analytical or experimental proof of concept | Calculation note (CAL), working build123d model with STEP export, drawing sheet (DWG), priced BOM with every unit cost filled in, prototype build plan (BLD) with pictures, `design_state: constructable` |
| 4 | Components validated in the lab | Test report (TST) with `environment: lab`, build log entries |
| 5 | Validated in a relevant environment | Test report (TST) with `environment: relevant` |
| 6 | System prototype demonstrated in a relevant environment | Precis at version 1.0 or later with status Released, a drawing at a lettered revision (Rev A or later), and a system-level TST with `environment: relevant` |
| 7 to 9 | Operational demonstration through proven in service | Beyond portfolio scope; claim only with a named deployment partner and evidence |

Rules:

- `project.yaml` records `trl` (current level), `trl_target` (the level the current effort aims for) and `trl_evidence` (the files that support the claim).
- `python .kit/render.py --check` fails if the evidence for the claimed TRL is missing. CI runs this check on every push.
- Documentation alone cannot go past TRL 3. TRL 4 and above require hardware and a test report.
- TRL and visibility are independent. A repo can be public at TRL 3 as a documented design ready to build.
- A change of TRL is recorded in the build log with the date and the evidence that justified it.

## 10. Portfolio phase and TRL cap

`.kit/PHASE.yaml` sets the current phase. During the **populate** phase every repo is capped at **TRL 3**: `trl` and `trl_target` may not exceed 3, and the check fails if they do. Every repo targets the cap: `trl_target` must equal 3, so a new repo is taken all the way to TRL 3 (scaffold, populate and advance, see `/to-trl3`). Work that belongs to TRL 4 or later (building or testing hardware, test articles, test plans and reports, build-log entries, purchasing lists, PCB layouts) must not be started. The prototype build plan (BLD, section 18) is TRL 3 paper work and is required. Where it already exists it is kept, flagged in the check output, and not extended. Only Amish changes `PHASE.yaml`.

Every repo carries a `CLAUDE.md` with the working rules for AI sessions: the TRL cap, decision rights (nothing is recorded as decided unless Amish decided it), one step per session, and a mandatory `docs/REVIEW.md` before stopping.

## 11. Concept media

Every repo at TRL 2 or above explains its idea visually. Media are generated from a build123d massing model with `.kit/concept.py`, never drawn by hand, so they stay in step with the design.

| File | Required | Purpose |
| --- | --- | --- |
| `media/hero.png` | TRL 2+ | Shaded isometric render with a 1.75 m person for scale; the website card image |
| `media/concept-blueprint.png` and `.pdf` | TRL 2+ | Blueprint concept sheet: orthographic and isometric views, scale, key figures, title block |
| `media/model.glb` and `media/viewer.html` | TRL 2+ | Interactive 3D viewer (glTF plus model-viewer) for the website |
| `media/cutaway.png` | When the inside matters | Section view showing internal parts |
| `media/exploded.png` | Recommended | Exploded view with numbered callouts matching the BOM |
| `media/flow.png` | When energy or material moves | System, energy or material flow diagram with losses |

Session commands in `.claude/commands/` (`/populate`, `/advance-trl3`, `/rein-in`, `/refresh-media`) carry the standard prompts, so every Claude Code session starts from the same instructions.

At TRL 2 a massing model is enough: correct overall proportions and main components. All concept media carry "CONCEPT, NOT FOR FABRICATION". The check warns when required media are missing at TRL 2 and fails at TRL 3.

## 12. Product renders

Every repo at TRL 3 shows the product as it would look, not only as a massing model.

- `cad/src/product_model.py` is the appearance model. It defines `product_parts()` (named parts with a shape and a material), `TITLE` ("Name: what it is") and `RENDER_VIEWS`. It is for renders only: every main dimension comes from `cad/src/model.py`, never typed in again.
- Where the appearance model departs from `model.py` (a chamfer, a label, a fastener drawn for realism), record the deviation in `docs/REVIEW.md` as "Proposed, awaiting Amish".
- Scale comes from context, not from a floating figure: a hand or forearm for handheld objects, and the posed mannequin (`mannequin()` in `.kit/context_parts.py`: stand, walk, push, ride, sit, reach) for anything a person uses at body scale.
- Renders are made with `.kit/export_views.py` (one scene per view) and `.kit/photoreal.py` (Blender Cycles), then captioned with `.kit/photo_caption.py`. Files are `media/render-<view>.png`; `media/render-hero.png` is required.
- Every caption names the project, the repository and the viewing direction, and carries "CONCEPT, NOT FOR FABRICATION".
- Captions never sit on the render. `.kit/photo_caption.py` adds a header band (title, concept label, repository) above the render and a footer band (view note) below it, wraps every line to the image width, and steps the font down to a floor before adding a line.
- The README opens with `media/render-hero.png`.
- Software-only and scene repositories (no single product) may use a scene render as the hero instead of a product model.

## 13. Storefront images

Two images, both made from `media/render-hero.png` by `python .kit/cards.py .`:

| File | Size | Purpose |
| --- | --- | --- |
| `media/card.png` | 800 x 800 | Square thumbnail for the organization profile page |
| `media/social-preview.png` | 1280 x 640, under 1 MB | GitHub social preview, shown when a repository link is shared |

- The social preview shows the area, name, one-line description, the first sentence of the pitch, the brand line and the repository address. Design Molecule repos read "Design Molecule · open hardware concept, TRL n"; OpenRatio repos read "OpenRatio · research and educational prototype, TRL n".
- GitHub has no API for the social preview. Upload it under the repository's Settings, Social preview, on release day.
- Regenerate both images whenever `render-hero.png` changes.

### Image quality

Every render, card and social preview must be clear and readable. `python .kit/image_qc.py` checks each one, and the release gate blocks on any failure:

| Check | Rule |
| --- | --- |
| Layout | Made by the current `photo_caption.py` or `cards.py`, which store the text layout in the PNG |
| Text inside the image | Every line at least 1.2 % of the image width from each edge; nothing runs off the side |
| No overlap | No line of text touches another line, and no caption text sits on the render |
| Text size | Render captions at least 1.05 % of the image width in pixel height (17 px at 1600 px); social preview text at least 16 px |
| Resolution | Renders at least 1200 px wide; card 800 x 800; social preview 1280 x 640 and under 1 MB |
| Sharpness | The render is not blurred or upscaled (edge sharpness at least 15 on the `image_qc.py` scale) |

Long titles and notes wrap to more lines rather than shrinking below the floor. The social preview shortens the pitch sentence with an ellipsis only if it cannot fit at the smallest size.

## 14. Public release

A repository goes public only when Amish approves it, and only after `python .kit/release_gate.py` passes. The gate checks:

1. `render.py --check` passes (document control, TRL cap, concept media).
2. Storefront: hero render, card, social preview under 1 MB, README leading with the hero, and every image passing the image quality check (section 13).
3. Issue templates in `.github/ISSUE_TEMPLATE/`: question, build report, design suggestion. The build report template restates that the design is a TRL 3 concept, not released for fabrication (OpenRatio: a research and educational prototype, not a medical device).
4. `CITATION.cff` valid, with an author ORCID.
5. License files match `project.yaml`.
6. No em dashes in the repository's own text.
7. BioMedical and OpenRatio repos use soft, non-clinical wording: "research and educational prototype, not a medical device".
8. No secrets anywhere in the history (gitleaks).
9. No links to sibling repositories that are still private.
10. REUSE files present (`REUSE.toml`, `LICENSES/`, `.github/workflows/reuse.yml`) and `reuse lint` passes (section 16).
11. `CITATION.cff` names exactly one license, because Zenodo rejects a list (section 17).

It warns, without blocking, when the README lacks a Safety heading or a "not for fabrication" statement, when `CITATION.cff` has no DOI yet, and when the README lacks the Zenodo DOI, REUSE or Software Heritage badge, so a person can confirm.

On release day, per repository:

- A signed, annotated tag `v0.<TRL>.0` on `main`.
- A GitHub release with short notes (what it is, TRL, status, licenses, how to cite) and a design pack, `<repo>-v0.<TRL>.0-design-pack.zip`, holding `cad/step`, `cad/drawings`, `docs/pdf`, `bom`, README, licenses and `CITATION.cff`.
- Description from the first sentences of `pitch` (350 characters at most), website `https://designmolecule.com` (OpenRatio: `https://openratio.ai`), topics from `project.yaml`.
- Before the first release, the repository is switched on in Zenodo (section 17), so the release is archived and gets a DOI.
- Visibility switched to public last, after the release exists.
- The social preview uploaded and the organization profile updated with the new cards.
- After the release: the concept DOI written to `CITATION.cff` and a Software Heritage save requested (section 17).

The internal working files (`CLAUDE.md`, `.kit/CLAUDE.md`, `.claude/commands/`, `docs/REVIEW.md`) stay public, and open "Proposed, awaiting Amish" items stay visible as open questions (Amish, 2026-09-27).

## 15. Authorship, citation and signing

- Amish Chadha is the author of every design, ORCID 0009-0000-8079-7141. Commits are authored as Amish Chadha <amish@designmolecule.com>.
- `CITATION.cff` lists Amish (with ORCID) first, then any credited contributors; `CONTRIBUTORS.md` and the README Credits section agree with it.
- `CITATION.cff` names one license: the hardware license (CERN-OHL-S-2.0), or the software license in a software-only repository. The full split between hardware and software licenses lives in `REUSE.toml` and the README. Once the repository is archived, `CITATION.cff` carries the concept DOI in `doi:`.
- Work done with Claude carries the trailer `Co-Authored-By: Claude <noreply@anthropic.com>` (with the model name), and the README Credits section says designs are developed with AI assistance.
- Every commit and tag pushed to GitHub is signed with Amish's SSH signing key, so GitHub shows it as Verified. Commits prepared elsewhere are re-signed on Amish's Mac before they are pushed.
- Once a repository is public, its history is never rewritten.

## 16. Licensing metadata (REUSE)

Every file states its copyright and license in a machine-readable way, following the REUSE Specification 3.3 (https://reuse.software). A repository is set up with:

```
python .kit/archive.py reuse
```

This writes three things and adds the REUSE and Software Heritage badges to the README badge line:

- `REUSE.toml`, built from the licenses in `project.yaml`. Everything is under the hardware license by default. Scripts, firmware, notebooks, web viewers, workflows and agent commands are under the software license. `cad/` and `electronics/` stay under the hardware license even where they are written as Python. The bundled IBM Plex fonts are OFL-1.1 (IBM Corp.). Copyright is "<first commit year> Amish Chadha".
- `LICENSES/`, with the full text of each license used (`reuse download`). The root `LICENSE` and `LICENSE-SOFTWARE` files stay for GitHub's license detection.
- `.github/workflows/reuse.yml`, which runs the REUSE check (fsfe/reuse-action) on every push and drives the README badge.

A new kind of file that falls outside these rules gets a new annotation in `REUSE.toml` rather than a header comment. `reuse lint` must pass before every commit that adds files, and the release gate enforces it.

## 17. Archiving and DOI (Zenodo and Software Heritage)

Every public repository is archived twice, so the design stays citable and retrievable if GitHub changes.

Zenodo (a citable DOI for each release):

1. Amish's Zenodo account is linked to GitHub. Before the first release, Amish switches the repository on in Zenodo (Account, GitHub). Only Amish changes Zenodo or GitHub settings.
2. Run `python .kit/archive.py zenodo`: it makes sure `CITATION.cff` names one license and adds the Zenodo DOI badge, which uses the GitHub repository ID and always points at the latest version. Zenodo reads its metadata (title, authors with ORCID, license, keywords) from `CITATION.cff`, and rejects the whole archive when that file lists several licenses.
3. Publish the GitHub release (section 14). Zenodo archives it within minutes and mints two DOIs: a version DOI for that release and a concept DOI that stands for all versions.
4. Check the Zenodo record: title, author and ORCID, license, keywords. If Zenodo shows "Citation metadata load failed", fix `CITATION.cff`, validate it with cffconvert and publish a new patch release (for example `v0.3.2`); a failed release is never re-used.
5. Run `python .kit/archive.py zenodo --doi <concept DOI>` and commit, so GitHub's "Cite this repository" and every future archive carry the concept DOI. Every later release gets its own version DOI automatically; the concept DOI never changes.

Software Heritage (permanent source archive):

1. After the repository is public, request a save at https://archive.softwareheritage.org/save/ (origin type git, the repository URL). Anonymous requests are limited to about ten an hour, so batches are spread out.
2. The Software Heritage badge on the README resolves once the save is accepted and ingested. Later pushes are picked up by its regular crawl.

OpenRatio repositories follow the same steps when Amish approves their release.

## 18. Prototype build plan (BLD) and the constructable design

### Two design states

A design moves through two states, recorded as `design_state` in `project.yaml`:

- **Concept**: the design shows what the product does and that it works on paper (TRL 2 and the calculations of TRL 3). Parts may be simplified shapes that have never been checked for how they are made or how they join.
- **Constructable**: every part can be made with the stated process and material, and every part fits and fastens to the parts next to it. Nothing is left as a shape that cannot be cut, cast, bent, printed, machined or bought.

A repo reaches TRL 3 only when its design is constructable and its build plan shows how. Writing the build plan is how the design is made constructable: when a part cannot be made or cannot fit as modelled, change the model so it can (Amish, 2026-09-30: "fix the design assumptions to match and be physically feasible"), keep what the concept does, and record every change in a decision record "Design for construction" (DDR) and in the plan. Changes that alter what the product does, its pitch or its safety case are proposed, not made.

### What the build plan is

`docs/05-build-plan.md` (`PRJ-BLD-001`) tells a capable maker how to build the first proof-of-concept prototype, in order, component by component, and shows it in pictures. It is written before anything is built, states "Plan, not yet built" under the title and never claims results. Building and testing to it is TRL 4 work.

### Writing rules

- **Plain English.** Say "the steel plate the jack stands on", not a model parameter or variable name. No code identifiers, function names, parameter names or file paths in the body of the plan. Give sizes as numbers with units ("a 62 mm hole, centred 100 mm up from the bottom edge"). The only place file names appear is the closing "Where the numbers come from" list.
- **Pictures first.** Every component and every assembly step has a picture. A reader should be able to build from the pictures, with the words explaining what the pictures cannot show (order, force, tolerance, checks).
- **By component, in build order.** Each component is made and checked before the step that needs it.
- **Cost is not the focus.** One line in the overview may state the parts cost from the BOM; there is no cost or time section.

### Sections, in order

1. **What you are building**: the overview picture (every component pulled apart and numbered in build order) and one short paragraph.
2. **What changed to make it buildable**: a table of each change from the concept (what the concept had, what the constructable design has, why), with a picture where the change is visible. "None" if nothing changed.
3. **Making the components**: one subsection per made component, in build order, each with:
   - its making sketch (three views with overall sizes, a 3D view, where it goes, making notes), `cad/drawings/PRJ-DWG-1NN`;
   - what it is and what it is made from (material, stock size);
   - how to make it, as numbered steps (mark out, cut, drill, bend, weld, cast, print, machine, finish), with the sizes that matter;
   - how it fits the parts next to it: a close-up picture of the joint, which faces touch, what holds them (bolt, weld, pin, clip, glue), the gap or fit needed, and which side goes where;
   - the check before moving on.
   Bought components get a short subsection: what to buy (specification, not brand), and what to do to it (drill, trim, fit).
4. **Putting it together**: numbered assembly steps, each with a step picture (parts already fitted in grey, the part being fitted in colour with an arrow showing the way it goes in), the fasteners, and any hold point.
5. **First checks**: fit, movement, first power or first load, each tied to a requirement ID with a pass criterion. The plan lists them; a TRL 4 test report records them.
6. **Safety stops**: points where work stops (before energising, pressurising, loading, lifting or operating) and what must be true to carry on.
7. **Tools, skills and workspace.**
8. **Where the numbers come from**: the model, drawings, calculation note and BOM, by file name.

### Budgets are value-engineering targets

`budget_usd` in `project.yaml` is a hypothetical control target that keeps the design thinking along a value-engineering lens; it is not a spending limit (Amish, 2026-10-01: "the budgets are a hypothethical control target to ensure we are thinking along a value engineering lens. its ok to ensure wording reflects that the hypothesis budget was x - the real cost being accrued is y"). Write it that way everywhere: "Value-engineering target: USD X. Estimated cost of the constructable design: USD Y (USD Z over or under the target)." A cost requirement is reported against the target ("over the value-engineering target by USD Z"), never as a failure that needs a budget decision, and the design decisions register does not carry "raise the budget" decisions. Instead the register has a short **Value engineering** section: target, estimated cost, the main cost drivers and the savings worth trying.

### Decisions live in their own document

The build plan describes the design as it stands; it never lists outstanding decisions, open questions or items awaiting Amish (Amish, 2026-09-30: "don't log outstanding decisions in this build plan - that is not the place for it. that should be in a separate design document logged and named as such"). Those go in the **design decisions register**, `docs/06-design-decisions.md` (`PRJ-DEC-001`), which has two tables: open decisions (what is to be decided, options, recommendation, what it affects in the build, source record) and decisions made (date, decision, Amish's words where recorded, link to the decision record). Things to confirm when parts are bought (for example a panel's frame lip) are open items in the register too. The build plan may say "see the design decisions register" once, in its introduction.

### Pictures

Pictures are generated from the model by `cad/src/build_plan_media.py` using `.kit/build_views.py` (overview, component making sketches, joint close-ups, assembly steps), so they always match the model. They are written to `docs/05-build-plan/` and `cad/drawings/`. Look at every picture before committing: labels readable, nothing overlapping, the part in question clearly visible.

`render.py --check` at TRL 3 requires a BLD document, `design_state: constructable` in `project.yaml`, and `docs/05-build-plan/overview.png`.

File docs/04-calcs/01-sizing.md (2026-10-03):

---
doc_id: SSP-CAL-001
title: SunSpoke sizing calculations
project: SunSpoke
doc_type: Calculation note
version: "0.5"
status: Draft
date: '2026-10-02'
author: Amish Chadha
license: CERN-OHL-S-2.0
revisions:
- version: "0.1"
  date: '2026-09-25'
  author: Amish Chadha
  change: First TRL 3 sizing note (mass, energy and range, hill and motor heating, solar, SwapCell interface v0.3 items, fork and torque arms, cradle retention, braking, cost)
- version: "0.2"
  date: '2026-09-25'
  author: Amish Chadha
  change: Recommendations accepted by Amish (DDR-002). Motor thermistor derate added to section 4; costs updated for the thermistor motor and controller
- version: "0.3"
  date: '2026-10-01'
  author: Amish Chadha
  change: Constructable design (SSP-DDR-003). Mass, cradle retention (three band clamps over V-saddles, real band path), end stop and gate loads, fit check, cost against the value-engineering target
- version: "0.4"
  date: '2026-10-02'
  author: Amish Chadha
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

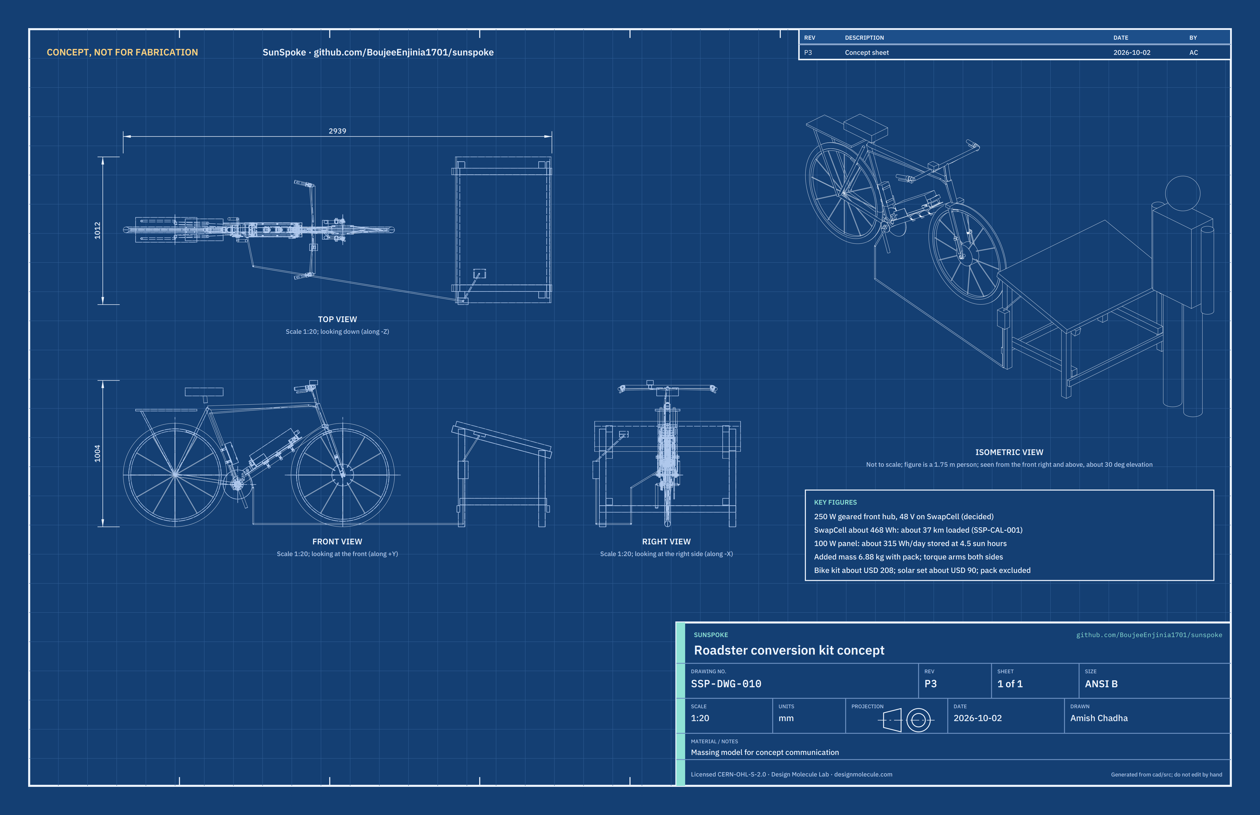
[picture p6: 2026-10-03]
media/concept-blueprint.png

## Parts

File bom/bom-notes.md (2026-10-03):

# BOM notes

**The SwapCell pack (item 6) is not included in the kit cost.** By Amish's portfolio rule of 2026-09-25, a SwapCell pack is priced once in the SwapCell repo ($414 in prototype parts, SWC-CAL-001) and excluded from each dependent kit budget. It is listed here so the numbering matches the exploded view and the full system cost is visible.

Every line is priced. Prices are indicative estimates with a supplier type, not quotes from named suppliers; they are checked by `docs/04-calcs/sizing.py` (SSP-CAL-001 section 11).

| Group | Items | Cost (USD) |
| --- | --- | --- |
| Bike conversion kit | 1 to 5, 7 to 9, 14, 15 | 208 |
| Solar charging set, costed separately | 10 to 13 | 90 |
| Kit plus solar set, pack excluded | 1 to 5, 7 to 15 | 298 |
| SwapCell pack (priced in SwapCell) | 6 | 414 |
| Full system for one rider with own panel | all | 712 |

R12 was redefined by Amish's decision of 2026-09-25 (SSP-DDR-001): the bike kit must cost USD 250 or less, and the solar set is costed separately. Value-engineering target: USD 250 (`budget_usd`, a hypothetical control target, not a limit). Estimated cost of the constructable design: USD 208 (USD 42 under the target). Generic parts make up about 84 % of the kit plus solar set cost.

On 2026-09-25 Amish accepted the remaining recommendations (SSP-DDR-002): the motor now has a built-in winding thermistor ($70 to $72) and the controller a thermistor input with a current derate ($22 to $25), so the bike kit rose from $183 to $188. The handlebar power switch in the INTERLOCK loop (item 8) was already costed.

On 2026-10-01 the design was made constructable (SSP-DDR-003): line 2 (torque arms) became a made part at USD 6; line 4 (cradle) rose from USD 28 to USD 33 for the aluminium tray, V-saddles, a third band clamp, the hinge and the draw latch; line 12 (panel stand) from USD 10 to USD 14 for timber and coach bolts; line 14 (hardware) from USD 8 to USD 11 for four more band clamps and the controller pad. The bike kit rose from USD 188 to USD 196 and the solar set from USD 86 to USD 90.

Decided by Amish on 2026-10-02 (SSP-DEC-001): the kit includes wet-weather brake blocks suited to steel rims, front and rear. They are now line 15 of `bom.csv`: two pairs at USD 6 a pair, USD 12 in all. The basis is an indicative price for a generic replacement block of the kind sold for rod and caliper rim brakes, not a quote. The assumed wet friction of 0.25 is also not verified; it is replaced by the maker's data or by a wet braking test (TRL 4, on hold). The blocks replace the donor blocks, so they add 0.10 kg to the kit in the mass count to be safe, and the bike kit rose from USD 196 to USD 208. The reference motor for line 1 is a widely sold 250 W front geared hub such as one of Bafang's, with 10 mm axle flats unless the donor survey shows 3/8 in slots are the norm, in which case a motor whose flats fit them is looked for first.

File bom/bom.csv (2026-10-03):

item | qty | spec | supplier | unit_cost_usd | make_buy | notes
1 Front hub motor wheel | 1 | 48 V 250 W geared front hub motor, slow winding (about 200 rpm no-load at 48 V), 100 mm dropout spacing, 10 mm axle flats, built-in 10 kOhm NTC winding thermistor wired to the controller, laced into a 28 in (ETRTO 635) steel rim with 13G spokes; donor tyre and tube reused | E-bike motor distributor (generic geared hub); rim and spokes from the local bike trade | 72.00 | buy | Generic part. Indicative price (motor with thermistor about $57; rim and spokes about $15); lacing by the local mechanic with a lacing card; 48 V decided (SSP-DDR-001); thermistor decided (SSP-DDR-002)
2 Torque arms (pair) | 1 | Two arms from 20 x 5 mm mild steel flat bar, 160 mm long, a 10 mm slot open at one end that fits the 10 mm axle flats, joggled 8 mm so the long part lies on the outside of the fork blade; each held 130 mm up its blade by a 12 mm stainless band clamp round blade and arm (clamps in line 14) | Local fabricator or the fitting mechanic (made); see SSP-DWG-107 | 6.00 | make | Generic part (local make). Indicative price; mandatory on both sides; design for construction SSP-DDR-003
3 Controller | 1 | 48 V nominal (to 54.6 V), 15 A battery current limit, sine-wave, potted or IP65 case, pedal-assist, brake cut-off, power-lock, walk-assist and motor thermistor inputs, current derate from 110 C winding temperature to zero at 120 C (no abrupt cutout), 20 km/h default cut-off | E-bike parts supplier (generic controller) | 25.00 | buy | Generic part. Indicative price; 15 A matches the SwapCell legacy limit; thermistor input decided (SSP-DDR-002)
4 SwapCell receiver cradle and clamps | 1 | Folded 3 mm 5052 aluminium tray with guide walls (1 mm clearance per side) and a latch ear; three 120 degree aluminium V-saddles with 1.5 mm rubber liners for 28 to 32 mm down tubes; three 12 mm stainless band clamps through slots in the tray; two HDPE slide strips; steel catch bar; folded 3 mm aluminium end stop carrying the SwapCell receptacle with its 10 kOhm 1 % INTERLOCK coding resistor; 3 mm steel drop-down gate with rubber pad on a stainless butt hinge, closed by an adjustable over-centre draw latch with safety catch (latch class V1, 330 N preload) | Local fabricator (tray, saddles, end stop, gate, strips, catch) plus hardware and connector suppliers | 33.00 | make | Portfolio-specific part. Indicative price; interface v0.3 items W and V; no welding and no drilling of the donor frame; design for construction SSP-DDR-003 (was $28)
5 Host adapter and charge port | 1 | Small microcontroller with CAN transceiver, supply diode-ORed from PACK+ and the charge port, controller power-lock output, keyed charge inlet, potted in a sealed box | Electronics distributor | 14.00 | buy | Portfolio-specific part (custom firmware). Indicative price; SwapCell vehicle host for modes 2 and 3 and mode 4 (interface v0.3 item C)
6 SwapCell pack | 1 | 13S2P 21700, 46.8 V nominal, about 468 Wh, 340 x 90 x 80 mm, about 2.85 kg (SwapCell interface v0.3) | SwapCell project | 414.00 | make | Excluded from the kit cost; priced once in SwapCell (SWC-CAL-001) per the portfolio rule
7 Pedal-assist sensor | 1 | Split 12-magnet disc that clamps on the bottom bracket spindle, and Hall sensor on a ring bracket that fits under the left lockring; fits without pulling the crank spindle | E-bike parts supplier | 6.00 | buy | Generic part. Indicative price
8 Handlebar control and brake cut-off | 1 | LED assist-level and charge display on its own bar clamp, power switch wired in series with the INTERLOCK loop, walk-assist button; two magnetic brake cut-off sensors on bar clamps beside rod or cable brake levers, with magnets glued to the levers | E-bike parts supplier | 14.00 | buy | Generic part. Indicative price; switch in the INTERLOCK loop decided (SSP-DDR-002)
9 Wiring harness with fuse | 1 | Waterproof keyed connectors (IP65 class), 20 A blade fuse in sealed holder, spiral wrap and cable ties | E-bike parts supplier | 15.00 | buy | Generic part. Indicative price
10 Solar panel | 1 | 100 W monocrystalline, about 1,000 x 670 x 35 mm, Vmp about 18 V | Regional solar distributor | 45.00 | buy | Generic part. Indicative price; can be shared at a village hub
11 Boost MPPT charger | 1 | Input 15 to 25 V, output CC/CV to 54.6 V at up to 2 A, input-voltage tracking, weather-protected case | Electronics distributor (generic boost charger module) | 25.00 | buy | Generic part. Indicative price; the host adapter is the SwapCell charge host
12 Panel stand | 1 | Timber A-frame from 45 x 45 mm treated sawn timber (two 700 mm top rails, two 668 mm rear legs, two 520 mm front legs, two 596 mm low braces) and two 935 mm 45 x 20 mm cross battens; 12 M8 x 100 coach bolts, four M6 panel bolts, wood screws; tilt 15 degrees | Local carpenter or the user (made); see SSP-DWG-108 to 110 | 14.00 | make | Generic part (local make). Indicative material cost; timber chosen over steel angle for the prototype (SSP-DDR-003; was $10)
13 Charge cable | 1 | 5 m, 2-core 1.5 mm2 outdoor cable with keyed plug to the cradle charge port | E-bike parts supplier | 6.00 | buy | Generic part. Indicative price; lets the pack charge in shade while the panel sits in sun
14 Hardware and consumables | 1 | Stainless bolts, nuts and washers (M4, M5, nyloc); countersunk screws; self-tapping screws for plastic; four 12 mm stainless band clamps for the torque arms and controller; 4 mm rubber pad for the controller; cable ties, spiral wrap and dielectric grease | Local hardware shop | 11.00 | buy | Generic part. Indicative price; no exploded-view callout; band clamps and pad added for construction (SSP-DDR-003; was $8)
15 Wet-weather brake blocks | 2 | Pair of brake blocks for steel rims in a wet-weather compound, rod-brake fitting, one pair for the front brake and one for the rear; they replace the donor blocks | Bike-trade retailer | 6.00 | buy | Generic part. Indicative price: about USD 6 per pair for rod-brake replacement blocks from bike-trade retailers, not a quote and not tied to a brand; wet friction assumed 0.25 in SSP-CAL-001 until the maker gives data or the wet braking test is run; decided 2026-10-02 (SSP-DEC-001)

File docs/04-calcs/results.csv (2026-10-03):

id | value | target | status
R3 | 100 °C winding at the top of 500 m from 35 °C (139 °C in the hot case); 32.6 N·m motor torque; 204 W motor; hot case derates after 223 m | 8 % for 500 m at 8 km/h at 35 °C; thermistor derate from 110 °C, no cutout | At risk
R4 | Slot filing about 0.24 mm per side on a 9.53 mm slot; fitting time not calculable | No fabrication; 90 min or less | At risk
R11 | 8.5 m dry (9 % margin); 21.8 m wet with standard blocks, 11.9 m wet with wet-weather blocks (assumed friction 0.25) | 9 m or less from 20 km/h, dry dirt; 14 m or less wet with wet-weather blocks (proposed value) | At risk
R7 | IP ratings by part selection only | IP65 electronics, IP54 motor, 150 mm water, 0 to 45 °C | Not verifiable at TRL 3
R9 | Generic parts 84 % of kit cost; swap time not calculable | Pluggable joints, 20 min swap, 70 % generic | Not verifiable at TRL 3
R10 | Arm clamp 154 N each, arm safety factor 4.2; 0.5 s cut-off needs a bench test | Brake cut-off, 0.5 s stop, fuse, torque arms | Not verifiable at TRL 3
R13 | Coding node 0.30 V; mode 4 net 1.39 A; clamp rotation margin 1.44 at 25 g | SwapCell interface v0.3 items W, C and V1 | Not verifiable at TRL 3
R1 | 250 W rated motor, 20 km/h cut-off, pedal assist and 6 km/h walk assist | 250 W; 25 km/h or lower; assist only when pedaling | Met (by specification)
R2 | 37 km (36 km with minimum cells) | 30 km or more | Met
R5 | Cradle for 28 to 32 mm tubes; motor for 100 mm spacing and 635 rim; pack fits the main triangle in the model | Common roadster | Met (on paper)
R6 | 6.88 kg | 7 kg or less | Met
R8 | 27 km/day; recharge 1.3 days (1.5 at 4 h) | 20 km/day; 2 days or less | Met
R12 | Bike kit $208 ($42 under the target); solar set $90 costed separately | Bike kit $250 or less (value-engineering target) | Met

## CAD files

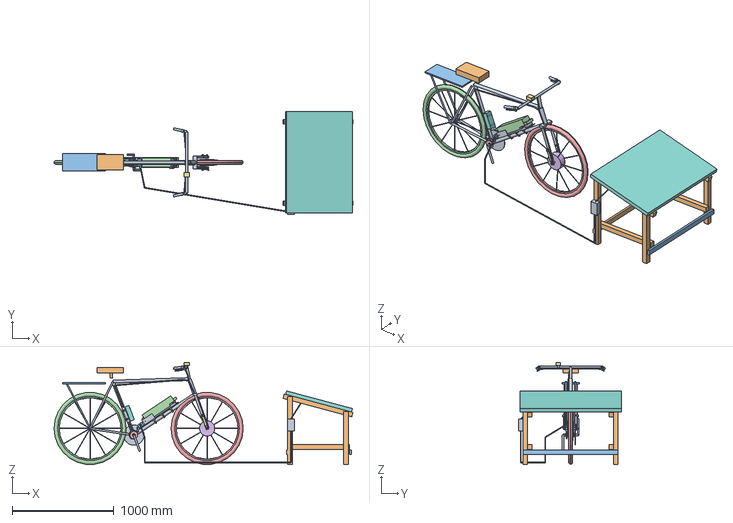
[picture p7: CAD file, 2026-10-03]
cad/step/sunspoke-assembly.step
2938.5 x 1012.5 x 1003.5 mm

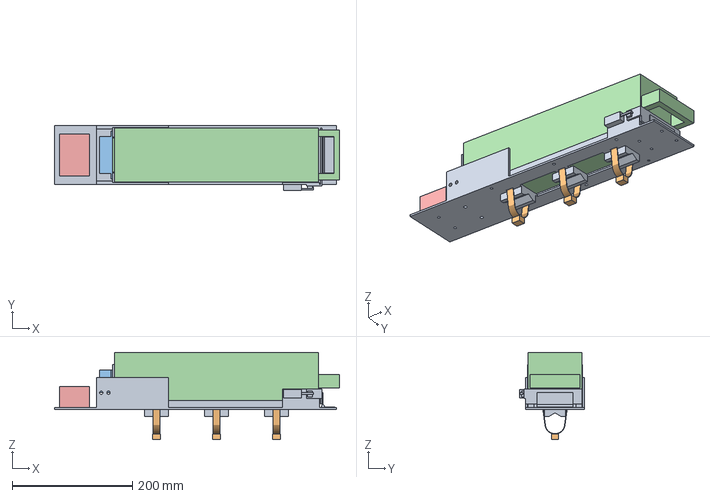
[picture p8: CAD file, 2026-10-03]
cad/step/sunspoke-cradle-with-pack.step
475.0 x 108.0 x 145.0 mm

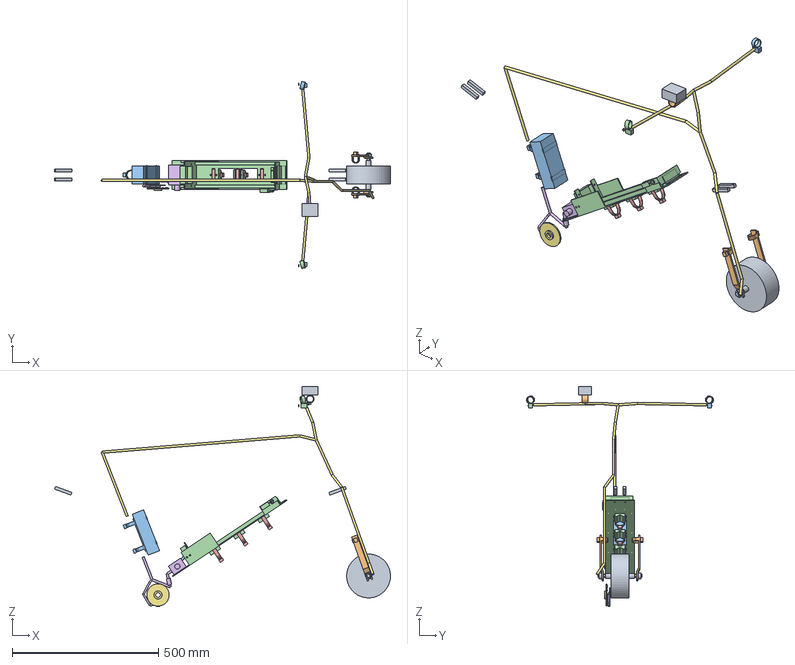
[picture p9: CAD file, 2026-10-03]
cad/step/sunspoke-kit.step
1148.9 x 639.5 x 753.5 mm

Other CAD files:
cad/stl/sunspoke-assembly.stl
cad/stl/sunspoke-cradle-with-pack.stl
cad/stl/sunspoke-kit.stl

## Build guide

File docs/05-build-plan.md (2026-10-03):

---
doc_id: SSP-BLD-001
title: SunSpoke prototype build plan
project: SunSpoke
doc_type: Build plan
version: "0.3"
status: Draft
date: '2026-10-02'
author: Amish Chadha
license: CERN-OHL-S-2.0
revisions:
  - version: "0.1"
    date: '2026-10-01'
    author: Amish Chadha
    change: First build plan, with pictures by component and step; design made constructable (SSP-DDR-003)
  - version: "0.2"
    date: '2026-10-02'
    author: Amish Chadha
    change: "Safety stop S7 adds the no-wet-riding rule decided by Amish on 2026-10-02"
  - version: "0.3"
    date: '2026-10-02'
    author: Amish Chadha
    change: "Wet-weather brake blocks added (line 15): new step 11, joint 11 (Figure 26), section 3.9.6, overview item 10; later steps renumbered 12 to 16; mass, cost and figures follow SSP-CAL-001 v0.5"
---

# SunSpoke prototype build plan

**Plan, not yet built.** How to build the first proof-of-concept prototype, component by component. Building and testing to it is TRL 4 work. Decisions still to be made are kept in the design decisions register ([docs/06-design-decisions.md](06-design-decisions.md)), not here.

## 1. What you are building

Figure 1. The kit on the bike, pulled apart and numbered in build order

*Figure 1. The kit on the donor bicycle, pulled apart and numbered in build order. The SwapCell pack (12) comes from the SwapCell project; the frame, fork and bars (13) are the rider's own.*

The prototype is one SunSpoke kit fitted to a 28 in steel roadster, plus its solar charging set. On the bike: a receiver cradle clamped to the down tube that holds a SwapCell pack, a 250 W hub motor laced into a new front wheel with a torque arm on each side of the fork, a sealed controller strapped to the seat tube, a pedal-assist sensor at the bottom bracket, a display and two brake sensors on the handlebar, four wet-weather brake blocks on the wheel rims, and a harness joining them. Off the bike: a 100 W panel on a timber stand with a charger and a 5 m cable to the bike. Figure 1 shows the 12 components in the order you fit them. Made in a small workshop: the cradle's tray, V-saddles, slide strips, catch bar, end stop and gate, the two torque arms and the panel stand. Bought and fitted: the motor, controller, sensors, display, brake blocks, harness, host adapter, receptacle, hinge, draw latch, band clamps, panel, charger and cable. The work is cutting, folding and drilling aluminium sheet, sawing and filing steel and aluminium bar, sawing and bolting timber, lacing a wheel, and plugging bought electrical parts together. Nothing is welded, and nothing is drilled or cut on the donor frame or fork. The bike kit parts cost about USD 208 and the solar set about USD 90, from the bill of materials.

> **Safety:** The kit runs from a 468 Wh lithium-ion SwapCell pack at up to 54.6 V DC, drives a loaded bicycle at up to 20 km/h, and puts new loads on an old steel fork. Keep the pack away from the bike and the fuse out until section 6 says otherwise. Cut aluminium and steel edges are sharp: deburr everything and wear gloves when handling sheet and bar. Never ride the prototype on a road; first rides are TRL 4 tests on a closed site.

### Choosing the donor bicycle

Pick a donor that the kit fits without any work on the frame or fork. It needs: a round down tube 28 to 32 mm across; front dropouts 100 mm apart inside, with slots that take the motor's 10 mm axle flats without filing (try a 10 mm gauge or the motor axle itself); a cup-and-cone bottom bracket with a lockring on the left cup; rod or cable rim brakes in good order, with the kit's four wet-weather blocks (step 11) to be fitted; and a fork and frame with no cracks, dents or rust through. Measure the step from the outside face of each dropout to the outside of its fork blade: the torque arms are made for 8 mm.

## 2. What changed to make it buildable

The concept showed what the kit does; many of its parts could not be made or fixed as drawn, and the pack could not be taken out. Each change below keeps what the kit does, and all of them are recorded in decision record SSP-DDR-003, open for Amish's review.

*Table 1. Changes from the concept.*

| Component | The concept had | The buildable design has | Why |
| --- | --- | --- | --- |
| Cradle base | A flat steel plate with a block cut into the down tube | A folded aluminium tray on three V-saddles with rubber liners (Figures 3 and 6) | The V seats on any 28 to 32 mm tube; aluminium keeps the mass down |
| Band clamps | Two rings round the tube passing through the plate | Three band clamps through slots in the tray, round the saddle and tube (Figure 6) | A band cannot pass through a plate; three bands keep the concept's grip with the real band path |
| End stop | A solid block with the receptacle inside it | A folded aluminium end stop with a plug notch, the bought receptacle bolted behind it (Figure 10) | It can be cut, folded and drilled by hand |
| V1 lever | Three loose blocks; the hinge block stood in the pack's way out | A drop-down gate with a rubber pad, on a hinge, closed by an over-centre draw latch (Figures 12 and 13) | Same preload and over-centre lock; folded down, nothing blocks the pack |
| Slide rails and catch | Steel bars and a block with no fixing | Plastic slide strips and a steel catch bar on screws (Figures 7 and 8) | Low friction; no screw heads where the pack slides |
| Host adapter | Floating beside the tube | On an extension of the tray, with a lead to the receptacle (Figure 2, step 4) | Uses the tray |
| Torque arms | Plates running into the fork blades; clips not joined to them | Joggled arms with an open slot on the axle flats, held by a band clamp round blade and arm (Figures 14 to 16) | The arm lies flat on the dropout and on the blade, as a torque arm must |
| Controller | Floating in front of the seat tube | On a rubber pad, held by two band clamps (Figure 22) | No drilling of the frame |
| Pedal-assist sensor | A disc on nothing and no sensor | A disc clamped on the spindle and a sensor on a bracket under the left lockring (Figure 23) | How bolt-on sensors fit this bottom bracket |
| Display and brake sensors | Boxes cutting into the bar | Each on its own bar clamp; magnets on the brake levers (Figure 24) | Fits the donor's own levers |
| Brake blocks | The donor's own blocks, which stop poorly in the wet | Four wet-weather blocks suited to steel rims, front and rear (Figure 26, step 11) | Standard blocks lose most of their grip on a wet steel rim |
| Harness | Running through open space and the cradle | Along the left side of the tubes on cable ties (step 12) | Clear of the cradle, wheel and cranks |
| Panel stand | Legs running into the panel; nothing holding the panel | A bolted timber A-frame; the panel bolts to its rails (Figures 17 to 21) | No welding, local timber |

## 3. Making the components

Make and check each component before the assembly step that needs it. Sizes are in millimetres. "Left" and "right" are as the rider sits on the bike. On the cradle, "lower end" is the bottom bracket end and "top end" the head tube end. Workshop tolerance is 0.5 mm unless a step says otherwise; drawings do not carry tolerances before TRL 4.

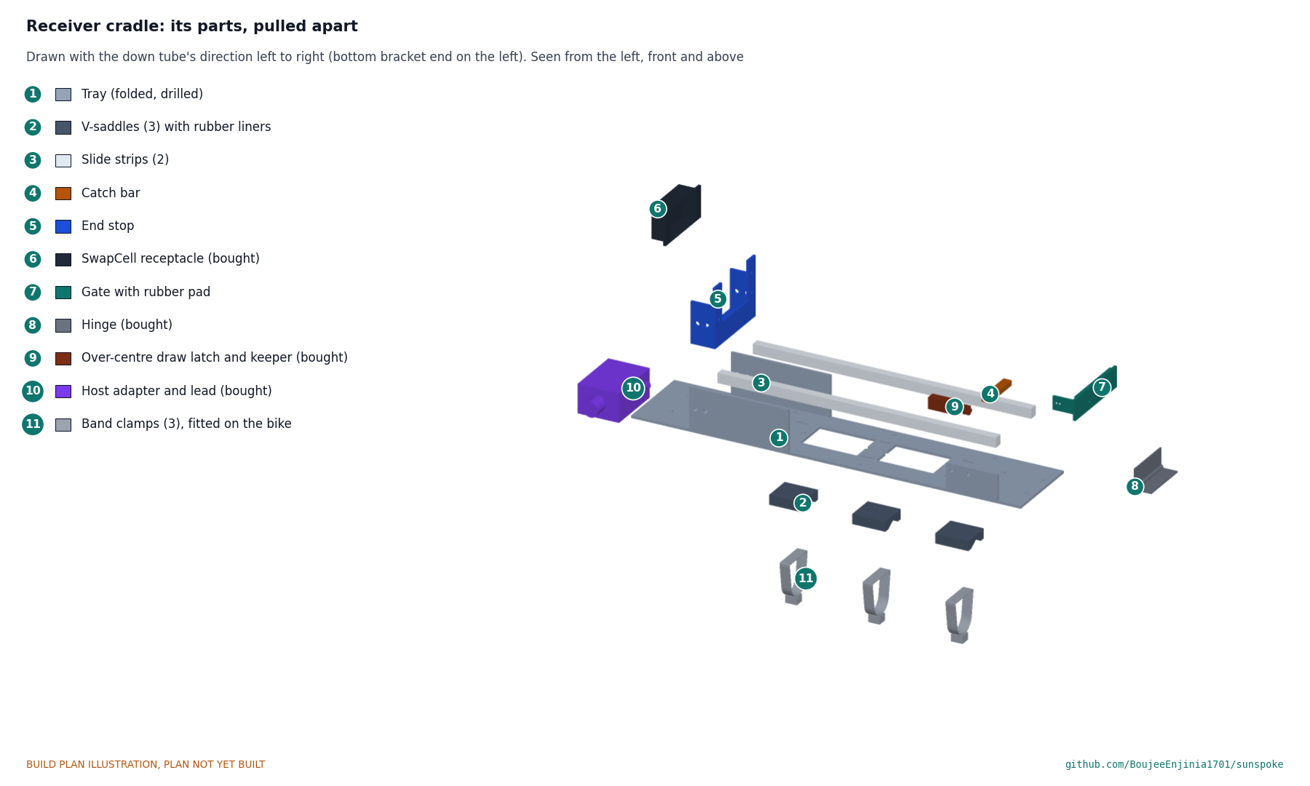
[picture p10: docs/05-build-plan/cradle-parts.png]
Figure 2. The receiver cradle's parts, pulled apart


*Figure 2. The receiver cradle's own parts (sections 3.1 to 3.6), pulled apart. It is built on the bench and clamped to the bike in step 5.*

### 3.1 Cradle tray

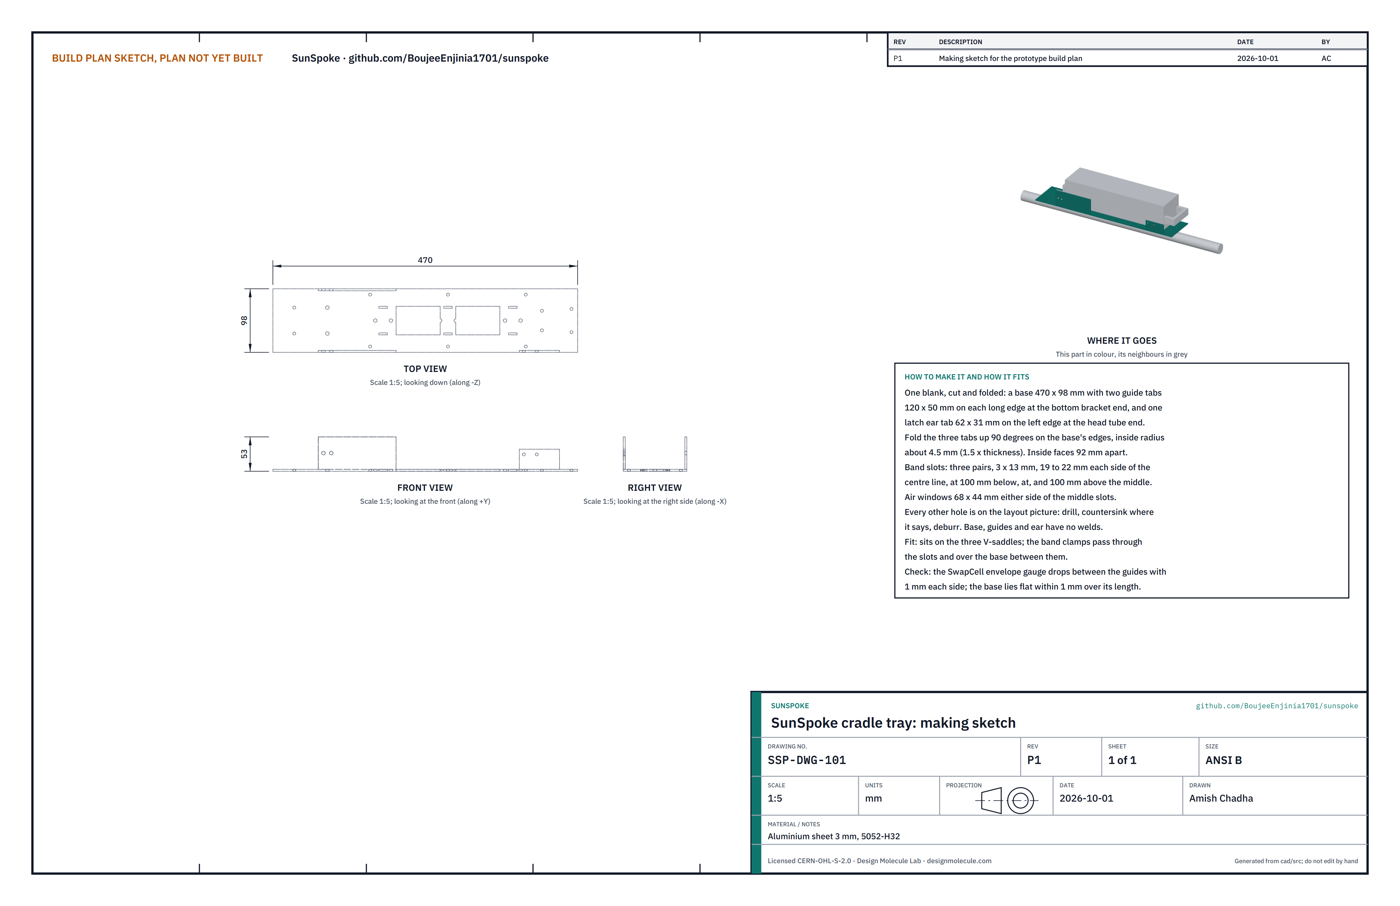
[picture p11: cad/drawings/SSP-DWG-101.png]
Figure 3. Making sketch of the cradle tray


*Figure 3. Cradle tray making sketch (SSP-DWG-101).*

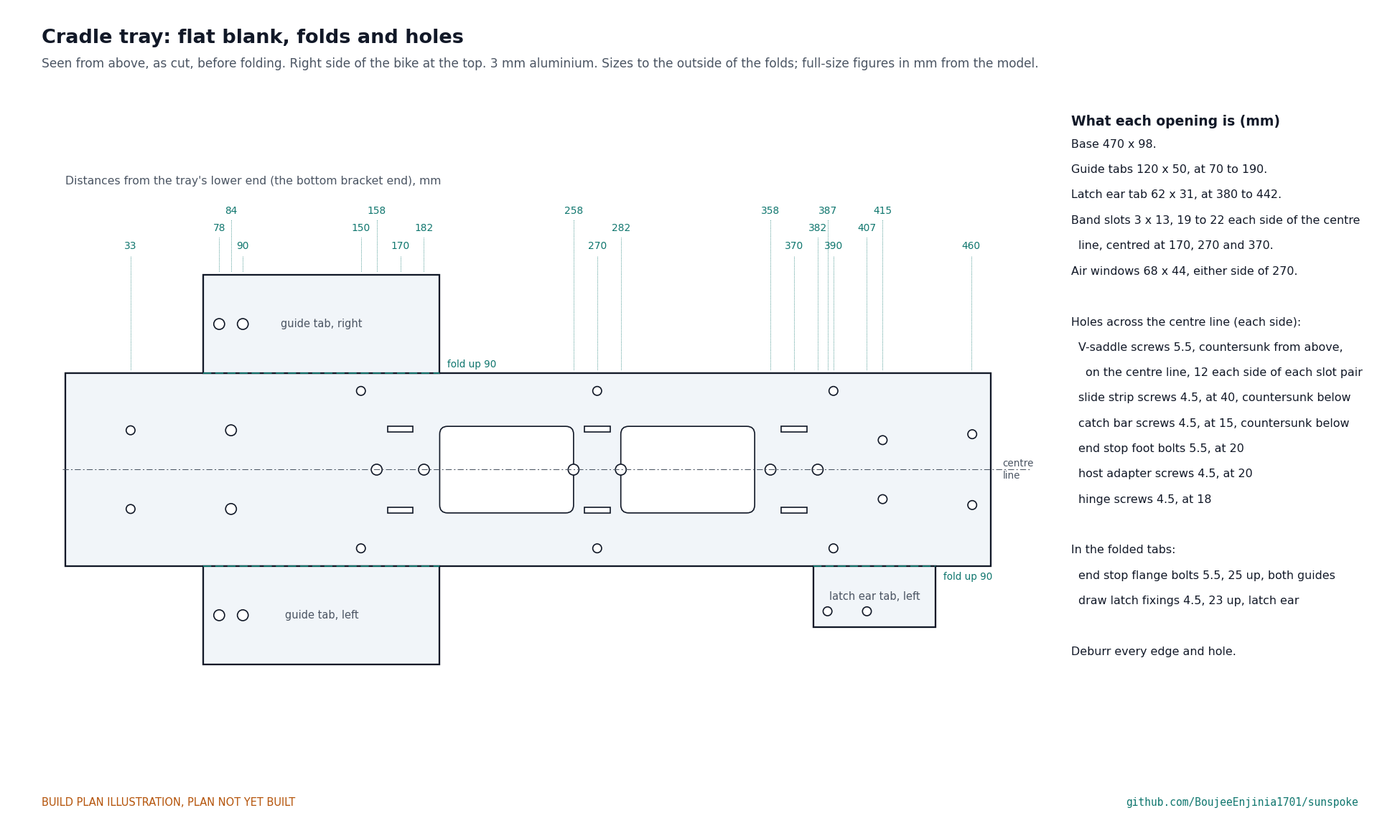
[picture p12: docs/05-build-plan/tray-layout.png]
Figure 4. The tray's flat blank, folds and holes


*Figure 4. The tray as cut, before folding, with every hole and fold, measured from its lower end and sideways from the centre line.*

**What it is and what it is made from.** The folded tray the pack slides on: a base, two guide walls at its lower end that keep the pack's connector lined up, and an ear at its top end that carries the draw latch. Aluminium sheet 3 mm, 5052-H32 (a grade that folds without cracking).

**How to make it.**

1. Mark the blank of Figure 4 on the sheet: a base 470 x 98 with two guide tabs 120 x 50, one on each long edge from 70 to 190 from the lower end, and a latch ear tab 62 x 31 on the left edge from 380 to 442. Cut it out with a jigsaw and a metal blade, or snips, and file the edges straight.
2. Drill a 3 mm relief hole at each inside corner where a tab meets the base, so the fold does not tear.
3. Mark and cut the six band slots, 3 x 13, a pair at each of 170, 270 and 370 from the lower end, 19 to 22 either side of the centre line: chain drill 3 mm and file square.
4. Cut the two air windows, 68 x 44, either side of 270, with 4 mm corner radii: drill the corners 8 mm and cut between with the jigsaw.
5. Drill every other hole in Figure 4. Countersink the six V-saddle holes from the top face, and the slide strip and catch bar holes from the bottom face.
6. Fold the three tabs up 90 degrees in a vice between two lengths of steel angle, over a 4.5 mm radius (a 9 mm rod). Check the inside faces of the guides are 92 apart and square to the base.
7. Deburr every edge and hole.

**How it fits the parts next to it.** The base sits on the three V-saddles (Figure 6); the band clamps go down through the slots and back over the base between them. The slide strips and catch bar sit on its top face, the end stop between the guides, and the latch on the outside of the ear.

**Check before moving on.** A SwapCell envelope gauge (or the pack itself, unpowered) drops between the guides with about 1 mm each side. The base lies flat within 1 mm along its length.

### 3.2 V-saddles (make 3)

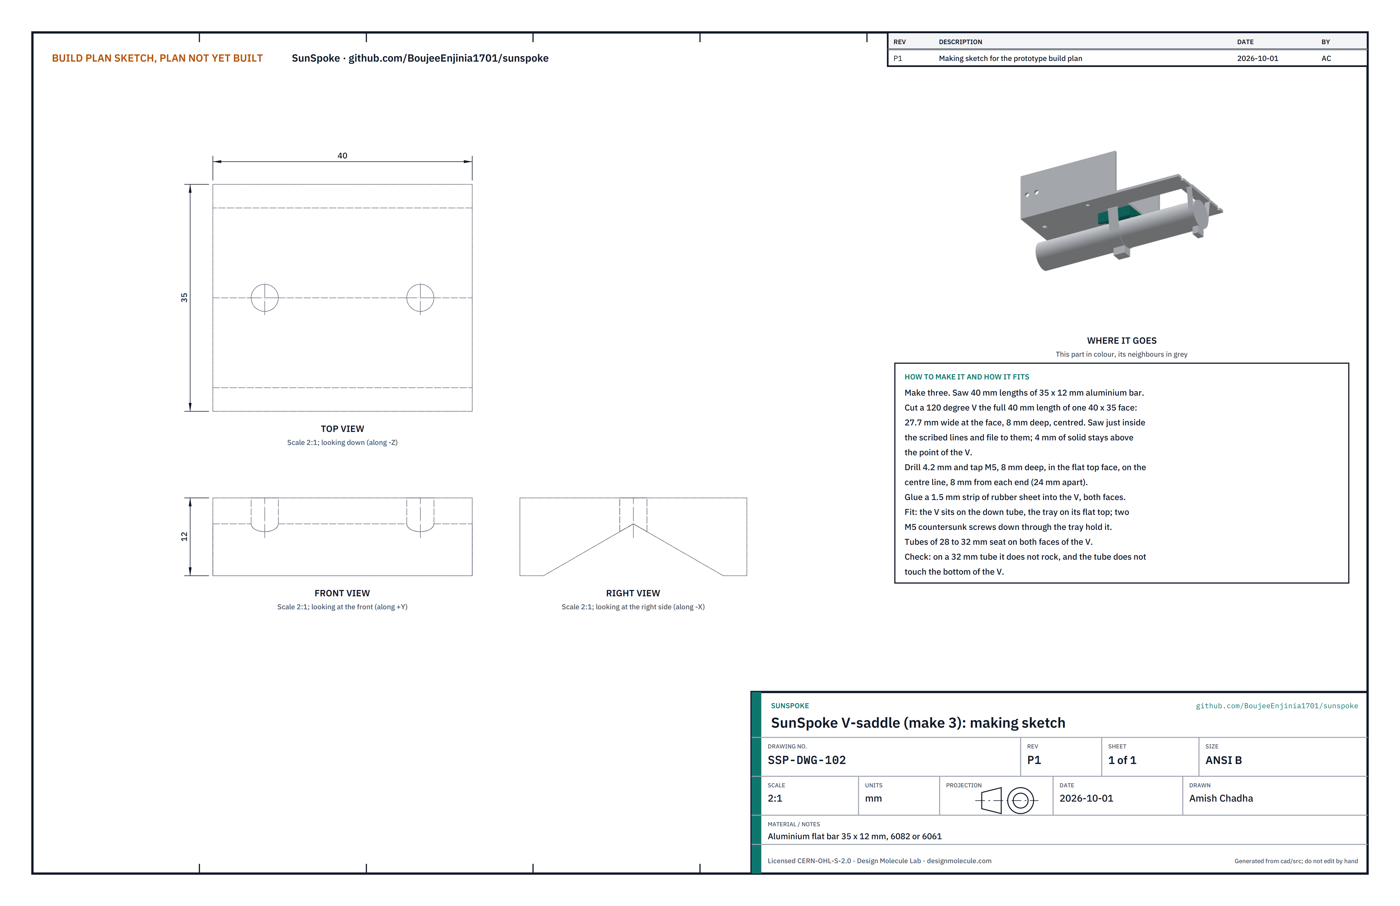
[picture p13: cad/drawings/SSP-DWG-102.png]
Figure 5. Making sketch of the V-saddle


*Figure 5. V-saddle making sketch (SSP-DWG-102).*

**What it is and what it is made from.** A short block with a wide V cut along its underside, one at each band clamp, that seats the tray squarely on the round down tube. Aluminium flat bar 35 x 12, 6082 or 6061, with a strip of 1.5 mm rubber sheet glued in the V.

**How to make it.**

1. Saw three 40 lengths of the bar and square the ends.
2. On one 40 x 35 face, scribe a 120 degree V running the full 40 length: 27.7 wide at the face and 8 deep, centred. Saw just inside the lines and file to them, leaving 4 of solid metal above the point of the V.
3. In the flat face opposite the V, drill 4.2 and tap M5, 8 deep, on the centre line, 8 in from each end (24 apart).
4. Glue a strip of 1.5 mm rubber sheet, 40 x 30, into the V with contact adhesive, covering both faces.

**How it fits the parts next to it.**

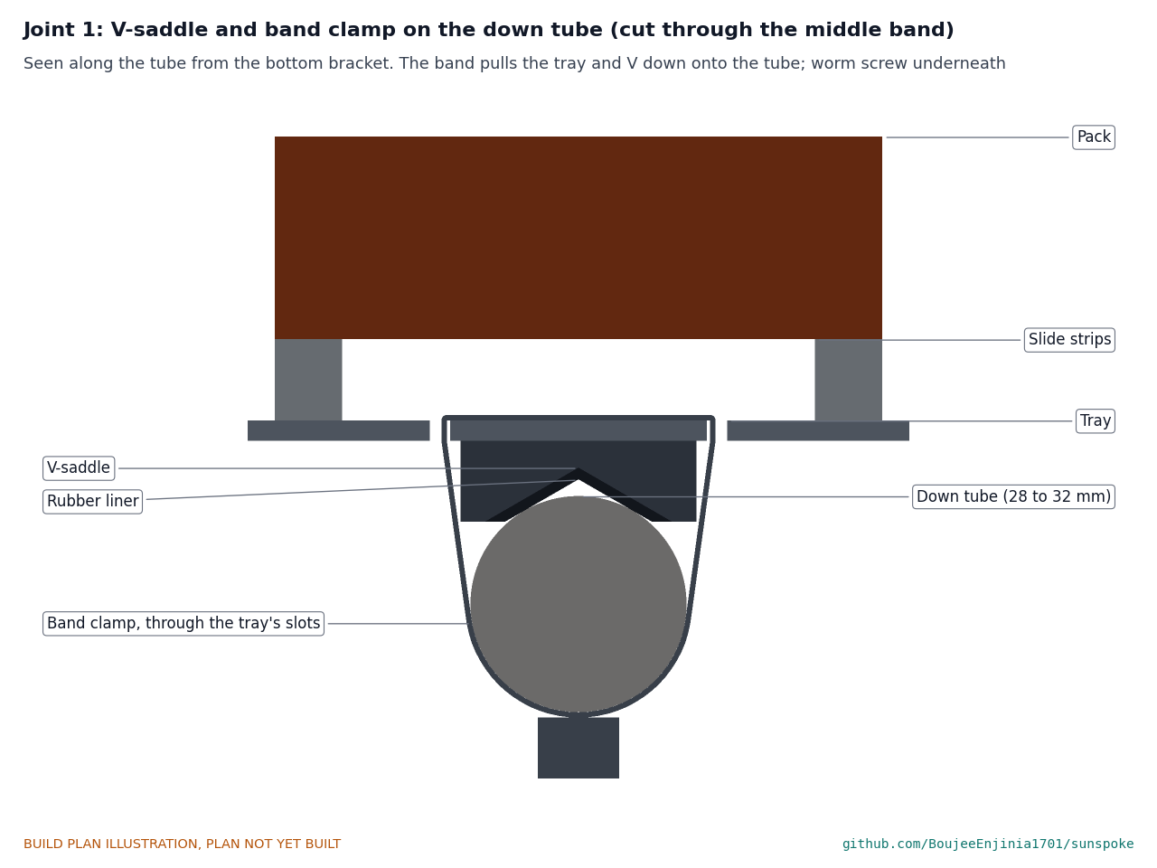
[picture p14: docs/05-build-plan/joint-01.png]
Figure 6. Joint 1: V-saddle and band clamp on the down tube


*Figure 6. Cut through the middle band, seen along the tube. The band runs from the tray's top face down through its slots, round the saddle and the tube, with its screw underneath; tightening it pulls the V onto the tube.*

The flat top of the saddle sits under the tray, held by two M5 countersunk screws down through the tray. The down tube bears on both faces of the V through the rubber and never touches the point of the V; tubes from 28 to 32 all seat this way.

**Check before moving on.** On a 32 tube the saddle does not rock, and you can see light at the point of the V but not along its faces.

### 3.3 Slide strips (make 2)

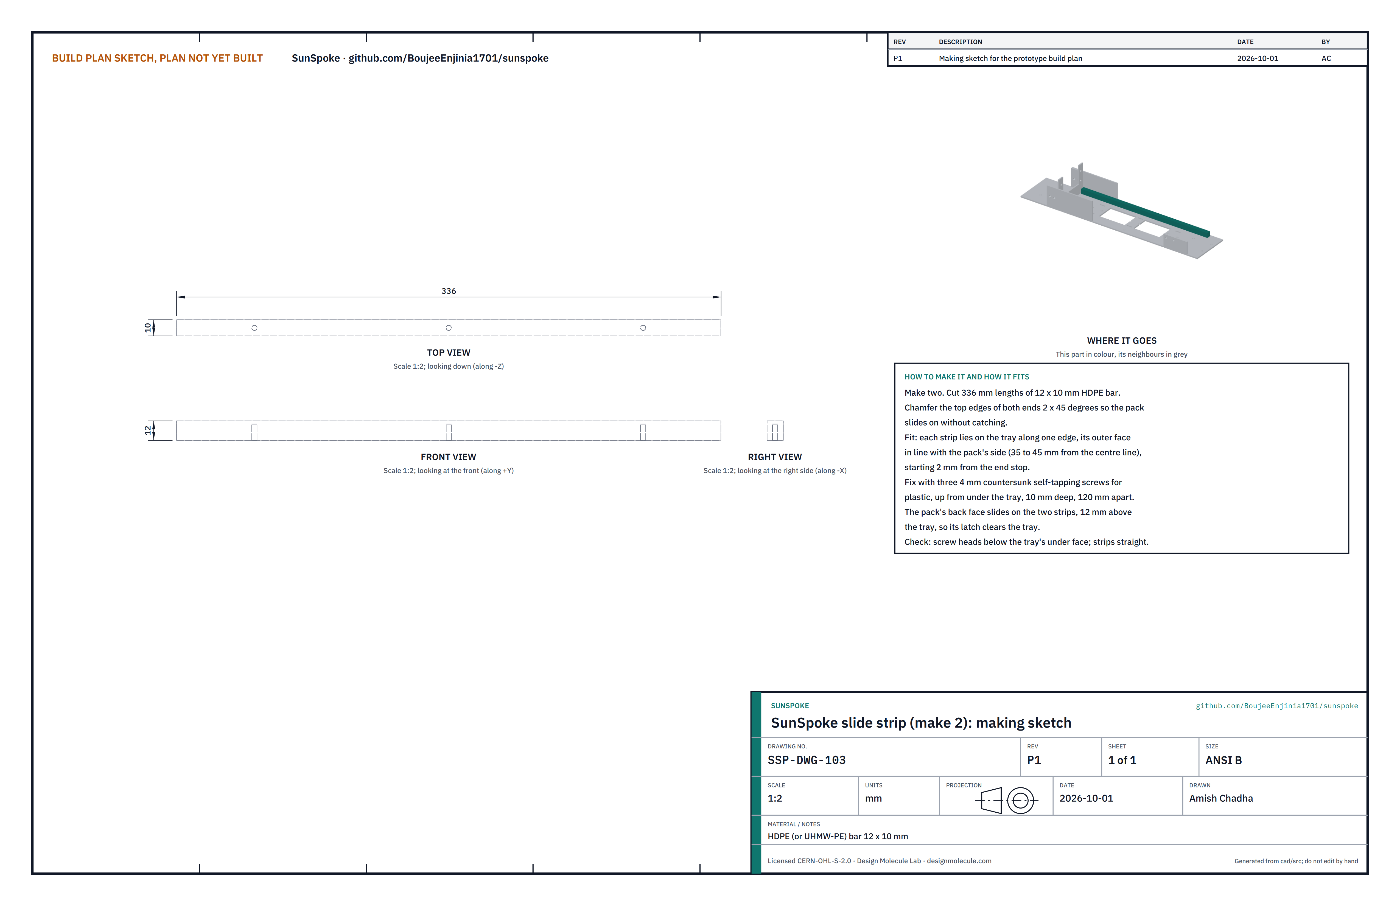
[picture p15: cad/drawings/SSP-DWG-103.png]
Figure 7. Making sketch of the slide strip


*Figure 7. Slide strip making sketch (SSP-DWG-103).*

**What it is and what it is made from.** Two plastic strips that the pack's back face slides on, holding it 12 above the tray so its own latch clears the tray. HDPE or UHMW-PE bar 12 x 10.

**How to make it.**

1. Saw two 336 lengths.
2. Chamfer the top edge of each end 2 x 45 degrees.
3. Lay each strip on the tray in place and mark its three screw holes through the tray from below; drill 3.2, 10 deep, into the strip.

**How it fits the parts next to it.** Each strip lies on the tray along one edge, 35 to 45 from the centre line, starting 2 from the end stop. Three 4 countersunk self-tapping screws for plastic go up through the tray into each strip; their heads sit below the tray's underside. The pack slides on the two strips (Figure 6).

**Check before moving on.** Both strips straight and the same height; no screw tip shows on the top face.

### 3.4 Catch bar

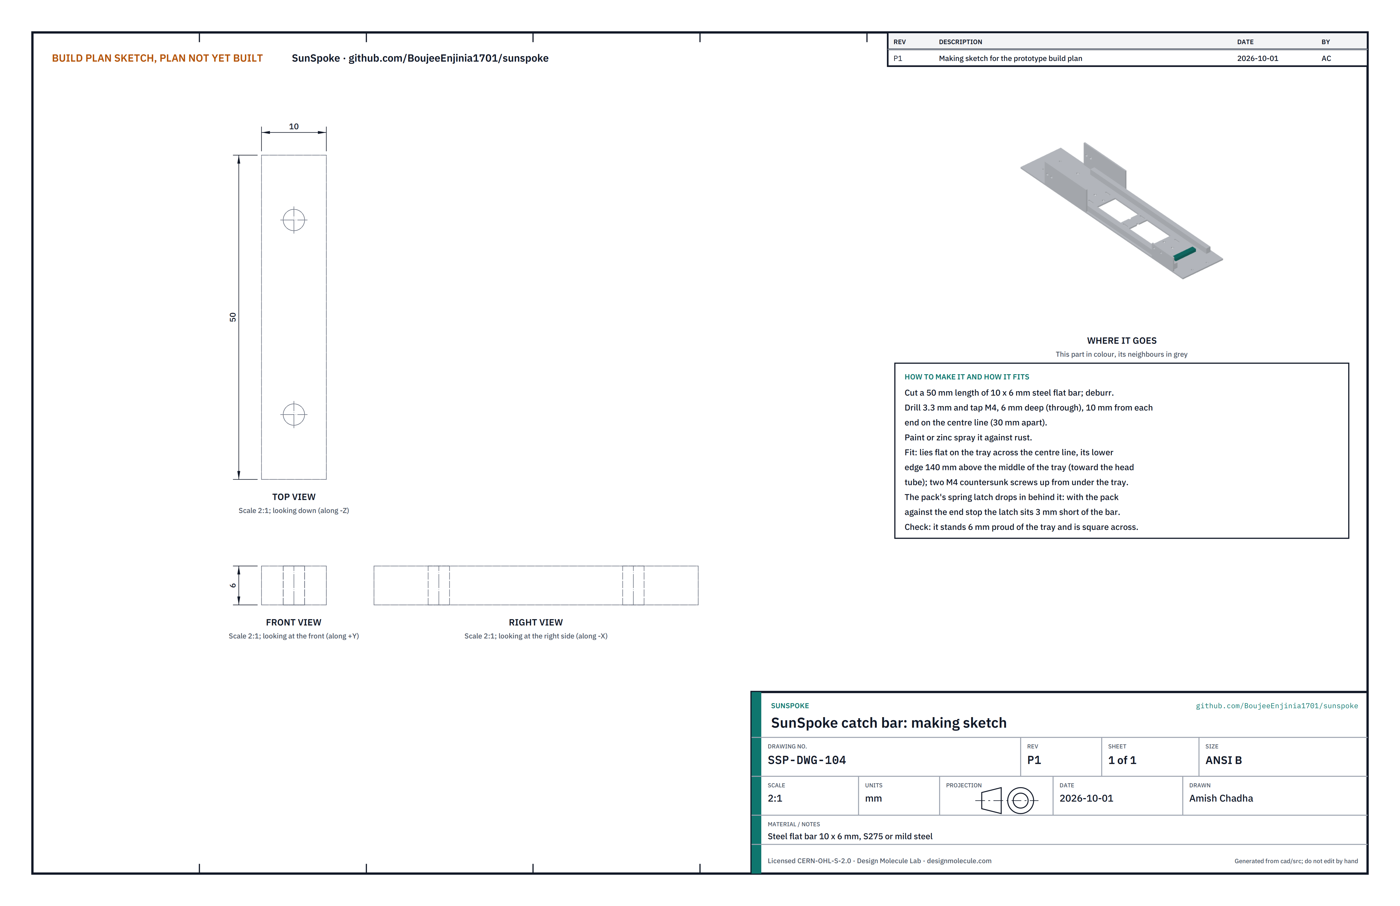
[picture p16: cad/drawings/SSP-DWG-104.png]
Figure 8. Making sketch of the catch bar


*Figure 8. Catch bar making sketch (SSP-DWG-104).*

**What it is and what it is made from.** A small steel bar across the tray that the pack's own spring latch drops in behind, so the pack cannot slide out if the gate is ever left open. Steel flat bar 10 x 6.

**How to make it.**

1. Saw a 50 length and deburr it.
2. Drill 3.3 and tap M4 right through, on the centre line, 10 in from each end.
3. Paint it or spray it with zinc.

**How it fits the parts next to it.** It lies flat across the tray's centre line, its lower edge 410 from the tray's lower end (140 above the middle), on two M4 countersunk screws up from below. With the pack against the end stop, its latch sits 3 short of the bar (Figure 12).

**Check before moving on.** It stands 6 proud of the tray and square across it.

### 3.5 End stop and receptacle

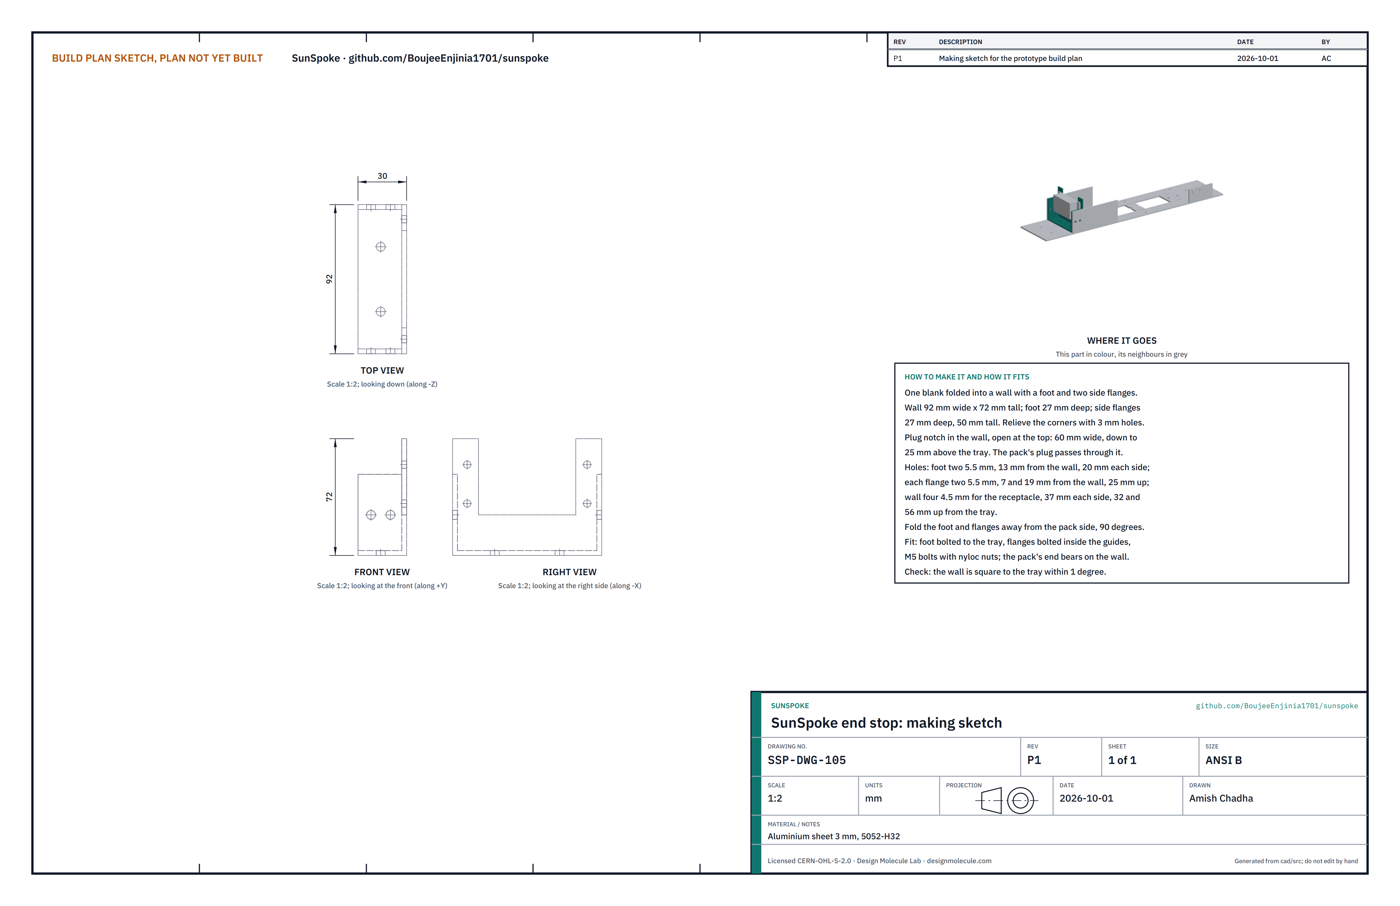
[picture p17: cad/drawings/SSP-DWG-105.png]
Figure 9. Making sketch of the end stop


*Figure 9. End stop making sketch (SSP-DWG-105).*

**What it is and what it is made from.** The wall at the tray's lower end that the pack is pressed against, with a notch the pack's plug passes through into the SwapCell receptacle behind it. Aluminium sheet 3 mm, 5052-H32, folded into a wall with a foot and two side flanges.

**How to make it.**

1. Mark one blank: the wall 92 wide x 72 tall in the middle, a foot 27 deep below it, and a side flange 27 deep x 50 tall on each side. Cut it out and drill 3 mm relief holes at the corners.
2. Cut the plug notch in the wall, open at the top, 60 wide, down to 25 above the bottom edge.
3. Drill: two 5.5 holes in the foot, 13 from the wall and 20 each side of centre; two 5.5 holes in each flange, 7 and 19 from the wall, 25 up; four 4.5 holes in the wall for the receptacle, 37 each side of centre, 32 and 56 up.
4. Fold the foot and both flanges 90 degrees away from the pack side.
5. Hold the receptacle against the back of the wall, its socket centred in the notch, and check its four holes line up.

**How it fits the parts next to it.**

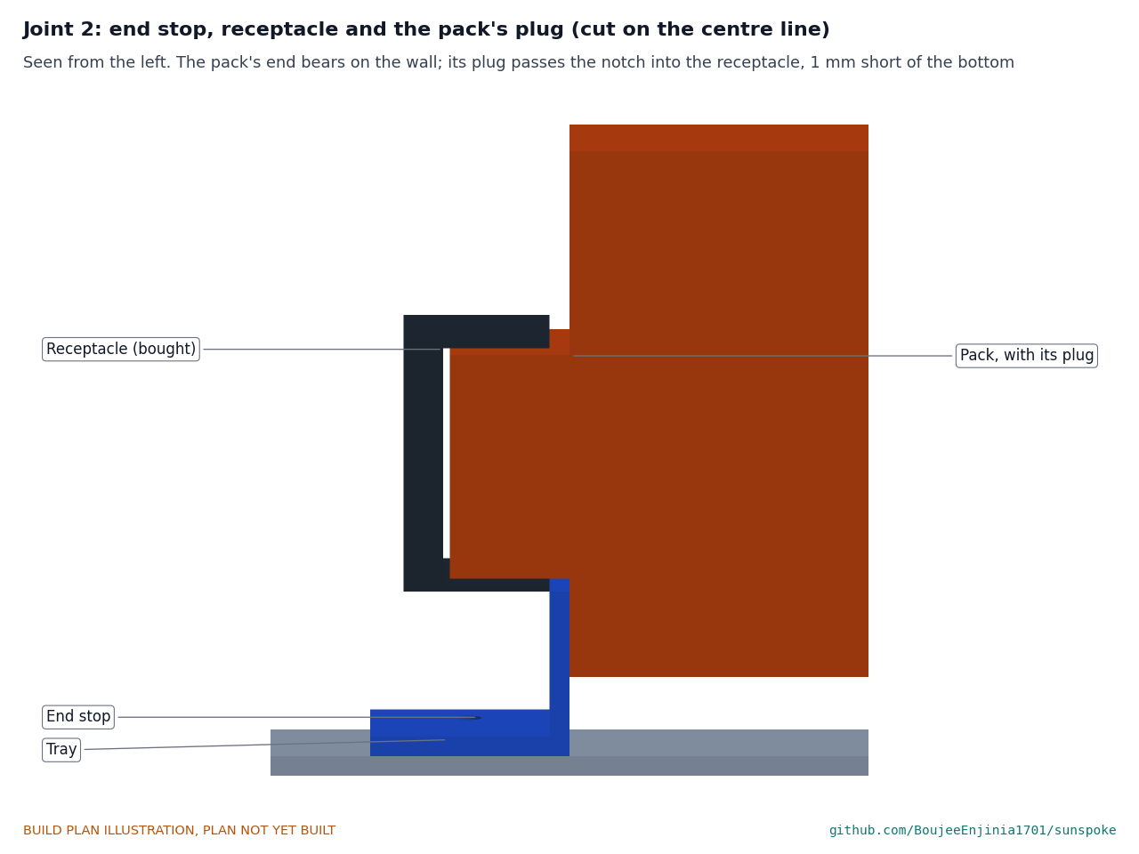
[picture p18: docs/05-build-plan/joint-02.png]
Figure 10. Joint 2: end stop, receptacle and the pack's plug


*Figure 10. Cut on the centre line, seen from the left. The pack's end bears on the wall; its plug passes the notch into the receptacle and stops 1 short of the bottom.*

The foot lies on the tray and the flanges against the inside of the guides, all on M5 bolts with nyloc nuts. The receptacle, with its 10 kΩ coding resistor already fitted by its maker, bolts to the back of the wall on four M4 bolts with nyloc nuts.

**Check before moving on.** The wall is square to the tray within 1 degree; the pack (unpowered) slides down onto the plug and seats on the wall without forcing.

### 3.6 Gate, hinge and draw latch

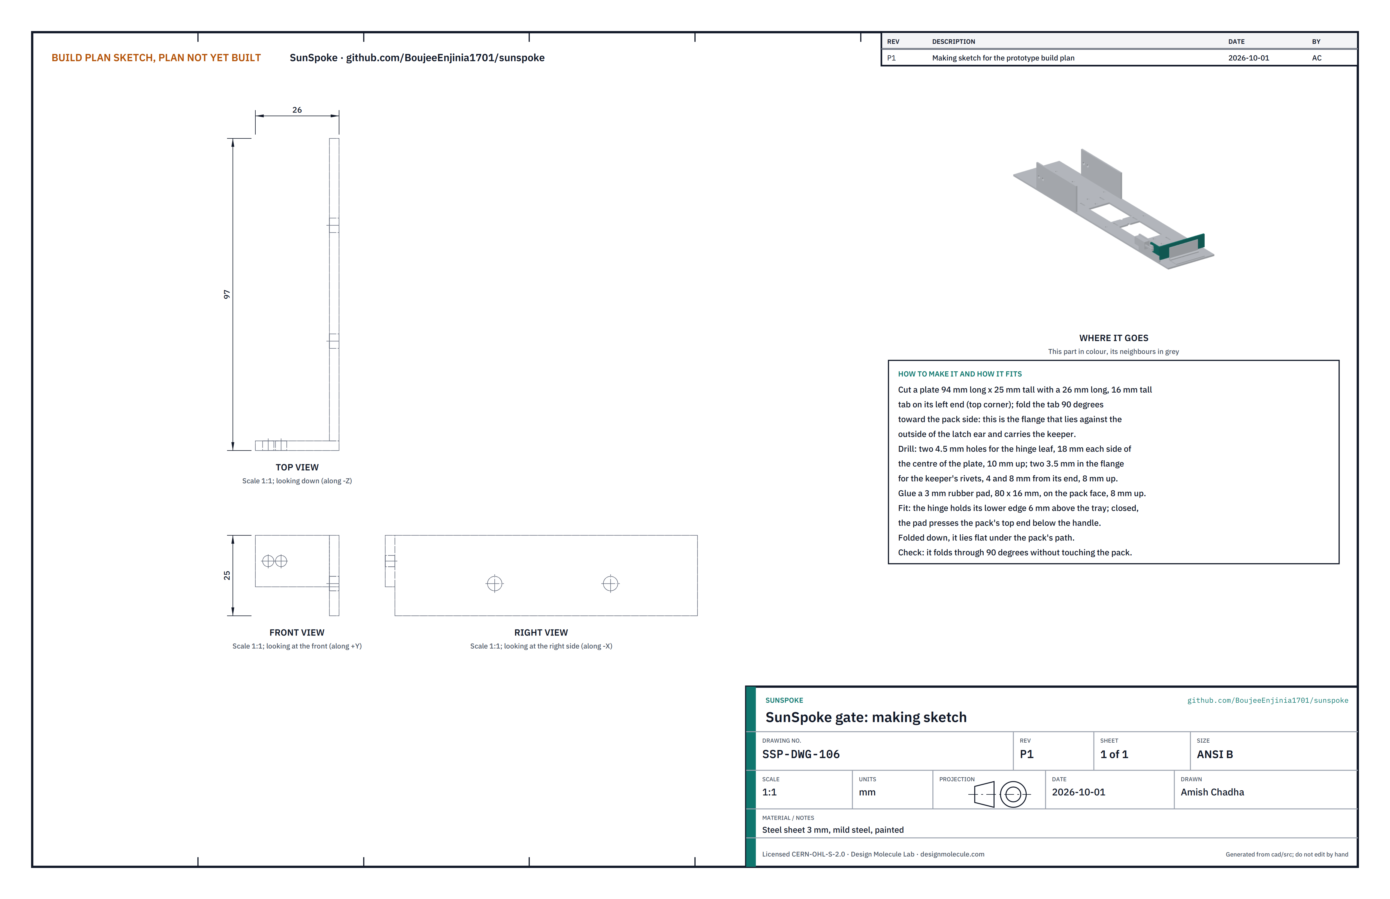
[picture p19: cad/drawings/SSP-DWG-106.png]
Figure 11. Making sketch of the gate


*Figure 11. Gate making sketch (SSP-DWG-106).*

**What it is and what it is made from.** The part that holds the pack against the end stop. A small steel plate on a hinge at the tray's top end presses the pack's top end through a rubber pad; an over-centre draw latch on the tray's left ear pulls it closed and locks with a safety catch. Opened, the gate folds flat so the pack can slide out over it. Steel sheet 3 mm; a stainless butt hinge 60 long; a stainless adjustable draw latch with keeper and safety catch; a 3 mm rubber pad.

**How to make it.**

1. Cut a plate 94 long x 25 tall with a tab 26 long x 16 tall on its left end at the top. Fold the tab 90 degrees toward the pack side: this is the flange that lies against the outside of the latch ear.
2. Drill two 4.5 holes for the hinge, 18 each side of the plate's centre, 10 up from its bottom edge; and two 3.5 holes in the flange for the keeper, 4 and 8 from its end, 8 up.
3. Paint it.
4. Glue an 80 x 16 rubber pad, 3 thick, on the pack face, 8 up from the bottom edge.
5. Rivet or bolt the keeper on the outside of the flange.

**How it fits the parts next to it.**

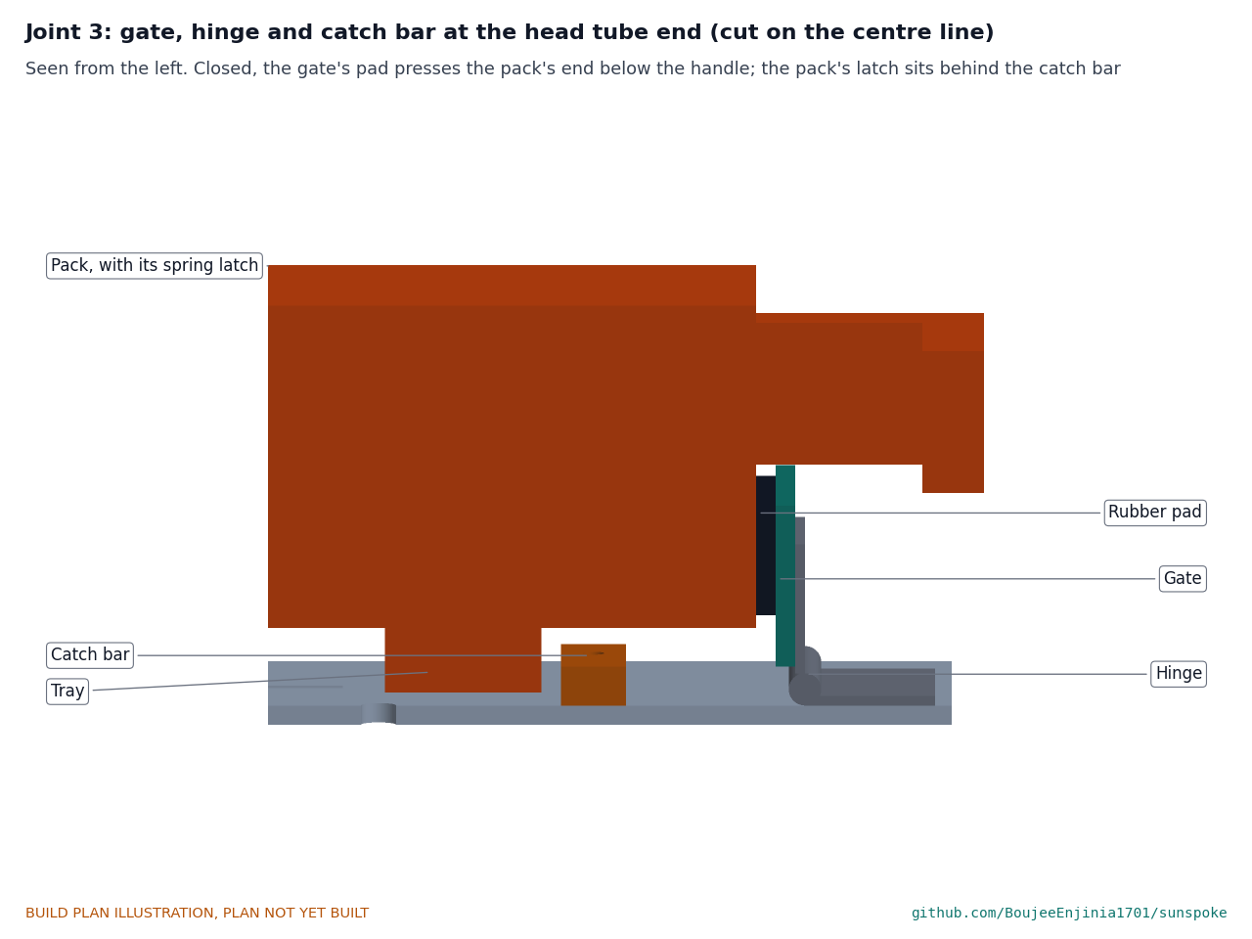
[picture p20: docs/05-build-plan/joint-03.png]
Figure 12. Joint 3: gate, hinge and catch bar


*Figure 12. Cut on the centre line, seen from the left. Closed, the pad presses the pack's top end below the handle, and the pack's latch sits behind the catch bar.*

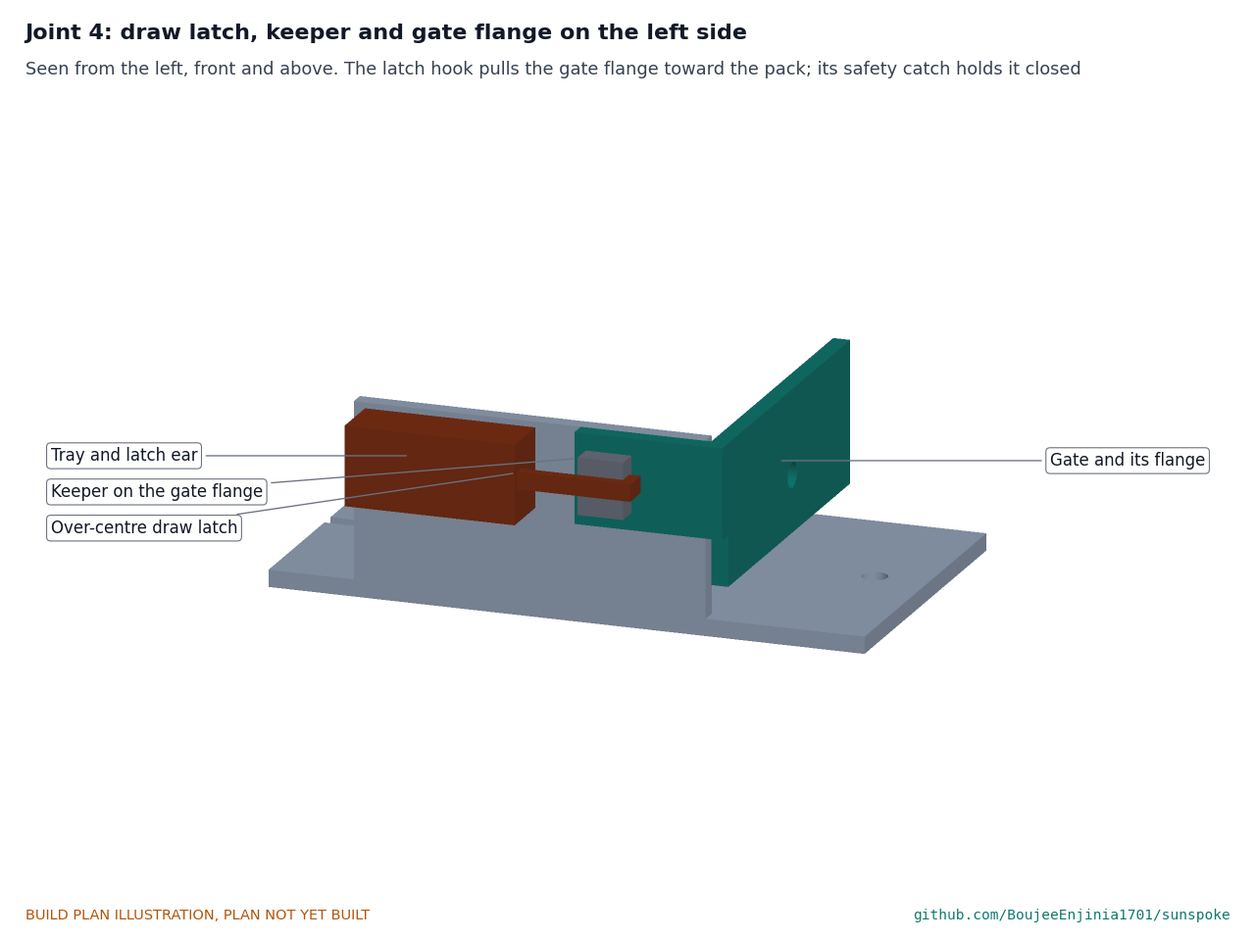
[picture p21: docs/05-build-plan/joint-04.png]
Figure 13. Joint 4: draw latch, keeper and gate flange


*Figure 13. The latch on the outside of the ear; its hook pulls the gate's flange toward the pack.*

The hinge's lower leaf lies on the tray 1.5 beyond the gate (two M4 bolts with nyloc nuts); its upper leaf lies on the gate's back face (two M4 bolts), holding the gate's bottom edge 6 above the tray. Closed, the gate stands 2 below the pack's handle and the flange lies against the outside of the ear. Adjust the latch hook so the latch needs a firm push to go over centre, then flip the safety catch; the preload it gives is measured in the first checks (section 5). Opened, the gate folds forward and lies flat on the hinge, below the strips.

**Check before moving on.** The gate folds through 90 degrees without touching anything; closed, the latch snaps over centre with one hand and its catch engages.

### 3.7 Torque arms (make 2, a left and a right)

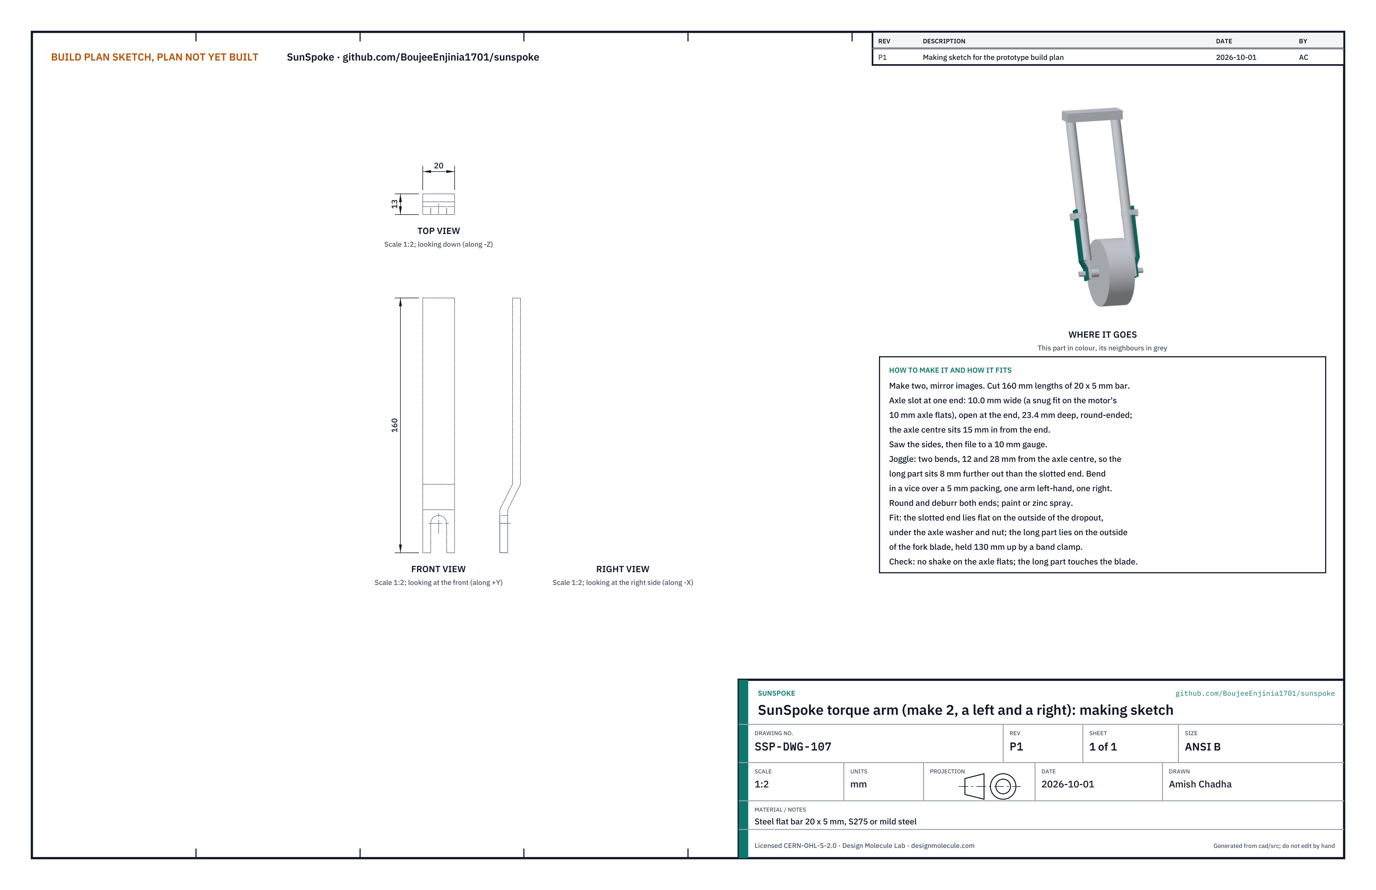
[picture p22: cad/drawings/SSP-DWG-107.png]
Figure 14. Making sketch of the torque arm


*Figure 14. Torque arm making sketch (SSP-DWG-107).*

**What it is and what it is made from.** An arm on each side of the fork that stops the motor's axle turning in the thin dropouts: its slotted end fits over the axle flats and its long end is clamped to the fork blade. Steel flat bar 20 x 5, S275 or mild steel.

**How to make it.**

1. Saw two 160 lengths.
2. Cut a slot in one end, 10.0 wide, open at the end and 23.4 deep with a round end: saw the two sides, break out the middle and file to a 10 mm gauge so it is a snug fit on the axle flats. The axle centre sits 15 in from the end.
3. Joggle each arm 8 in a vice: bend at 12 and at 28 from the axle centre, over a 5 packing, so the long part is offset 8 from the slotted end. Make one left-handed and one right-handed.
4. Round and deburr both ends; paint or zinc spray.

**How it fits the parts next to it.**

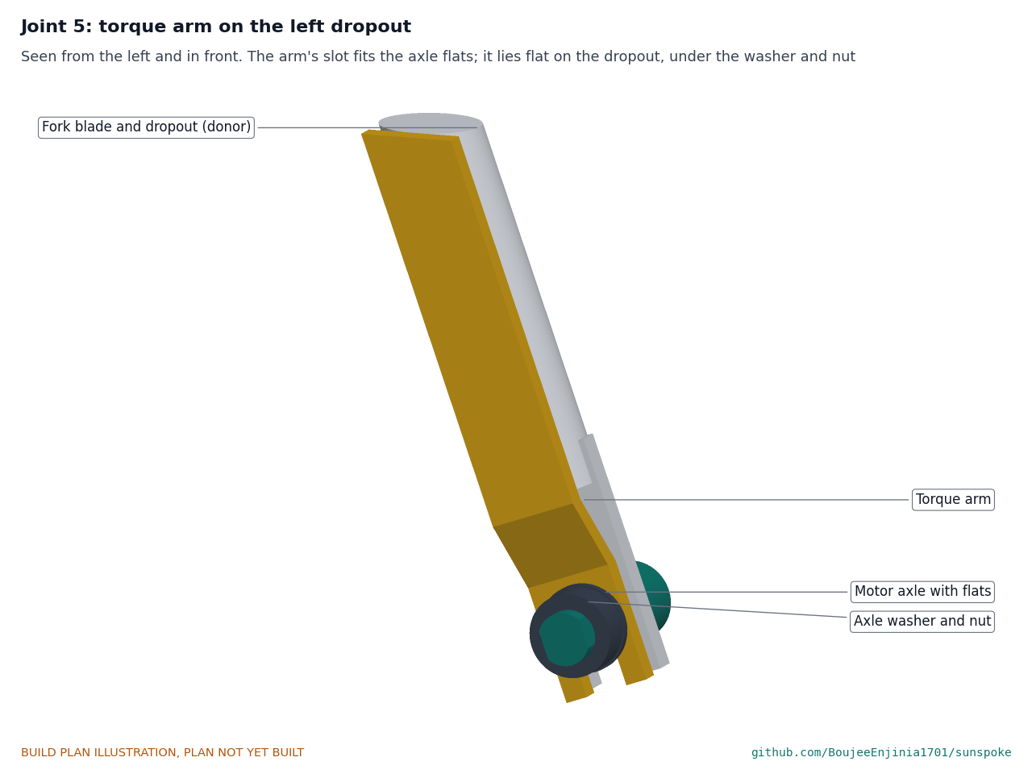
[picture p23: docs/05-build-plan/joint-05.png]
Figure 15. Joint 5: torque arm on the left dropout


*Figure 15. The slotted end lies flat on the outside of the dropout, keyed on the axle flats, under the washer and axle nut.*

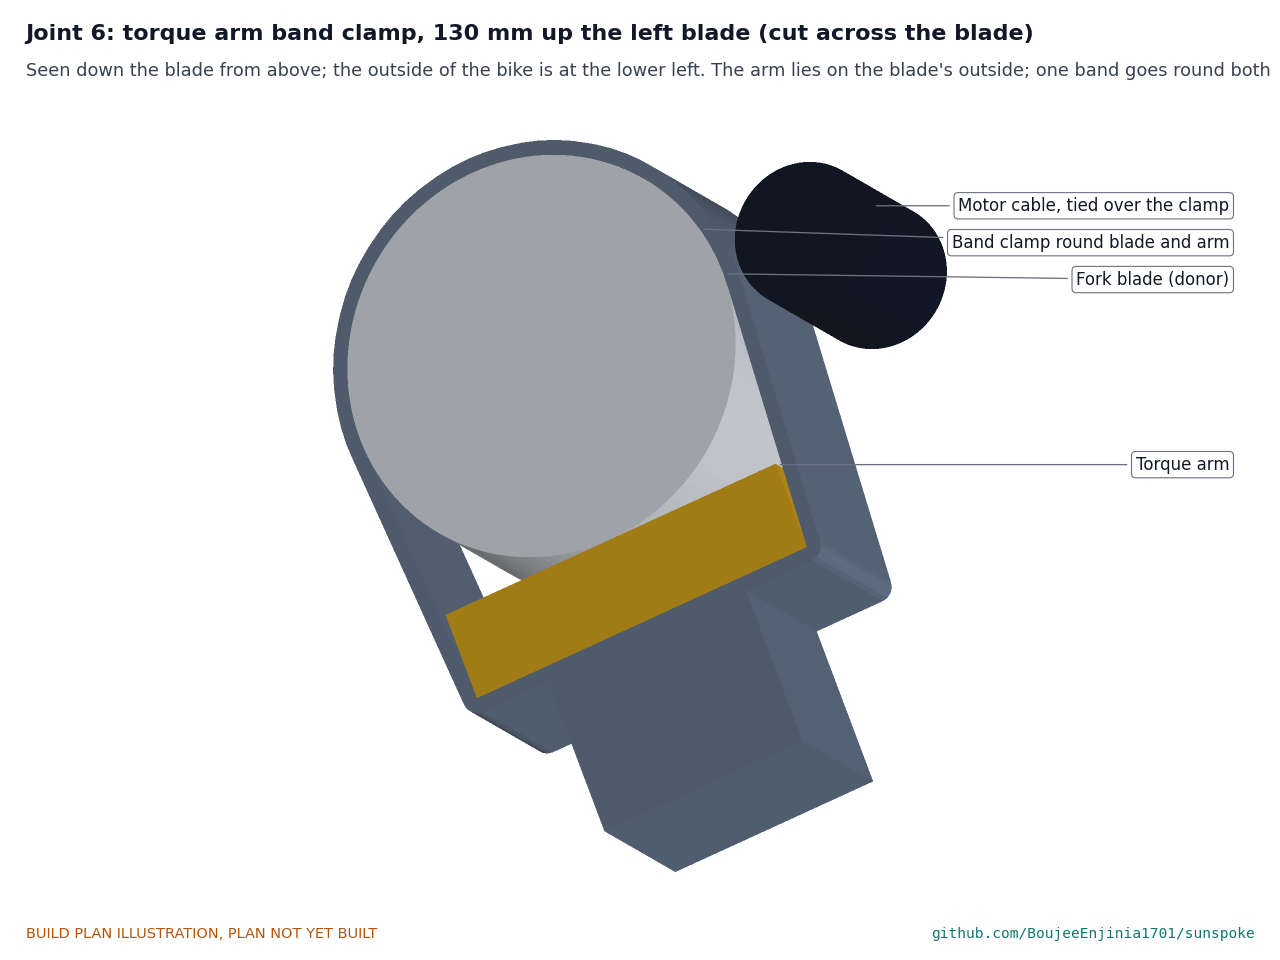
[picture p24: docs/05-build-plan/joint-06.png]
Figure 16. Joint 6: torque arm band clamp


*Figure 16. Cut across the blade, 130 up: the arm lies on the outside of the blade and one band clamp goes round both. The motor cable is tied over the clamp.*

The slotted end sits on the dropout's outside face, the axle washer and nut on top of it. The joggle takes the arm out past the blade so its long part lies against the outside of the blade, where a 12 band clamp 130 up the blade holds it.

**Check before moving on.** The slot slides onto the axle flats with no shake; on the donor, the long part touches the blade along its length with the slotted end flat on the dropout.

### 3.8 Panel stand

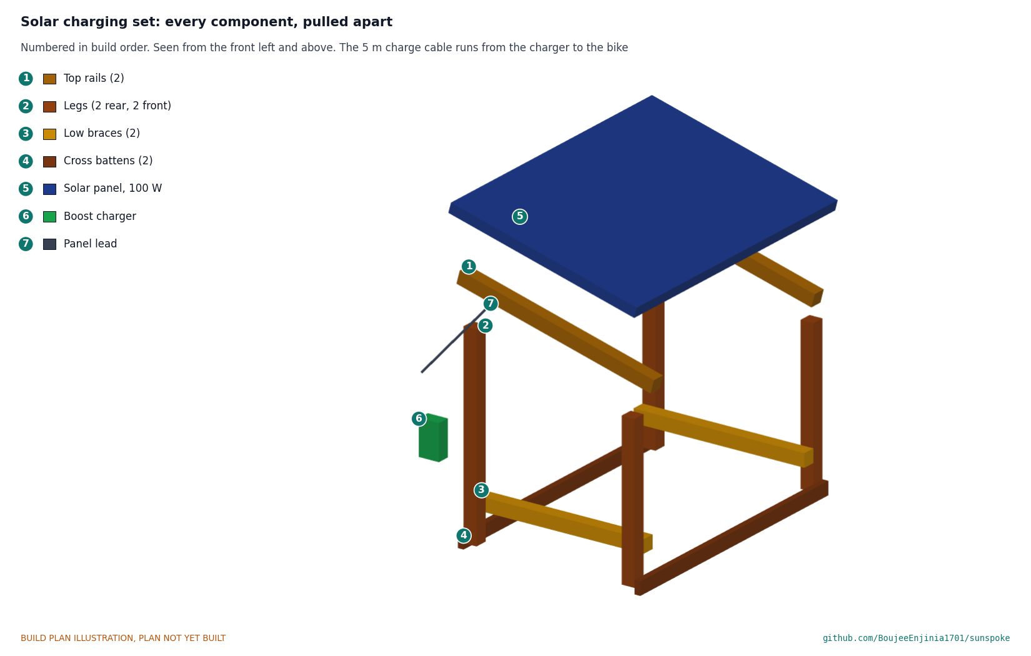
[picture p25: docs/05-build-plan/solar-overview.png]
Figure 17. The solar charging set, pulled apart


*Figure 17. The solar charging set, pulled apart and numbered in build order.*

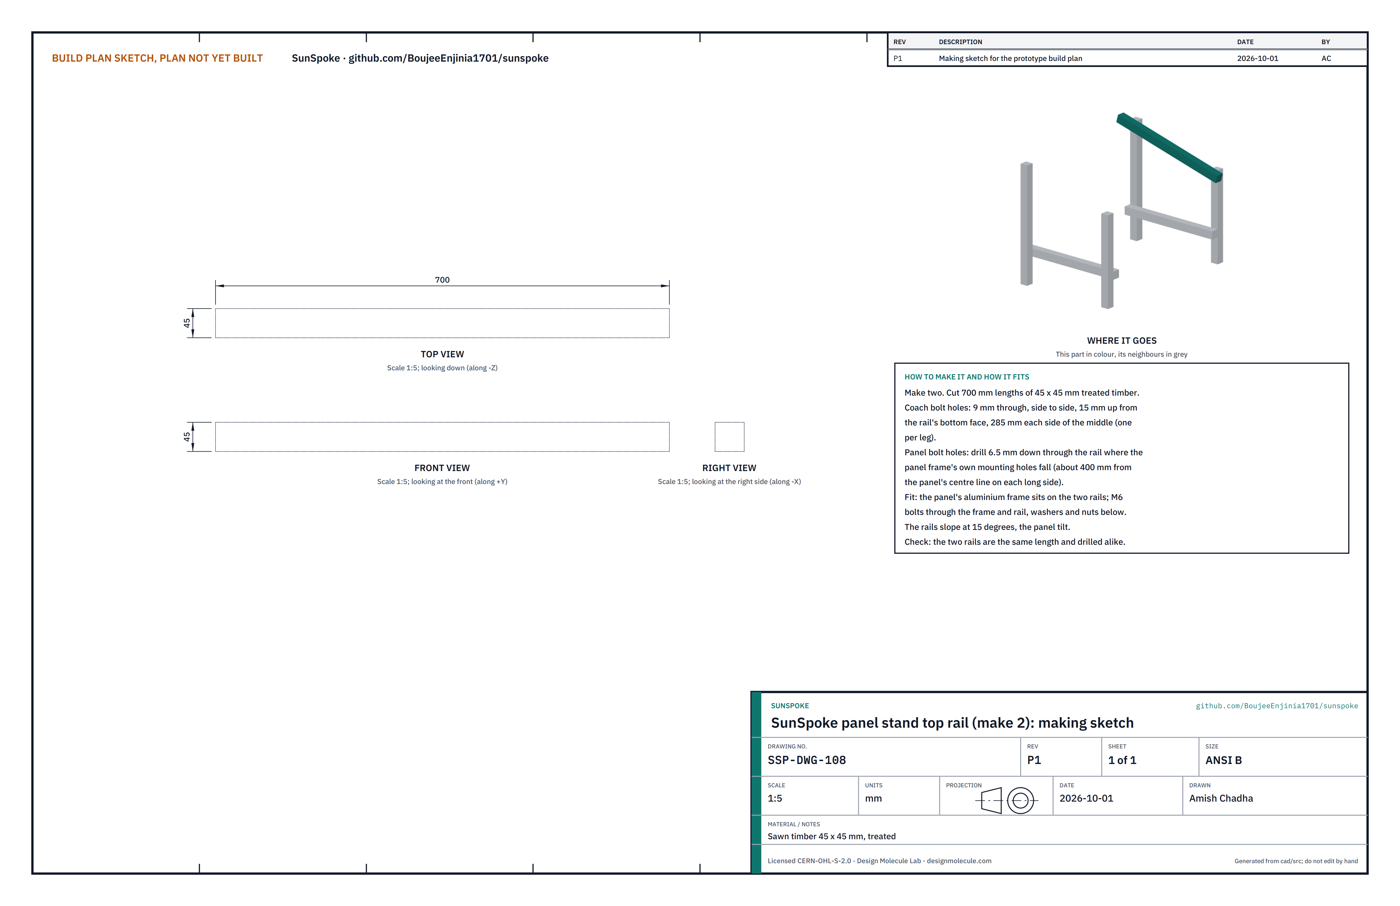
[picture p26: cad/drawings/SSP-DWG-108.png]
Figure 18. Making sketch of the top rail


*Figure 18. Top rail making sketch (SSP-DWG-108).*

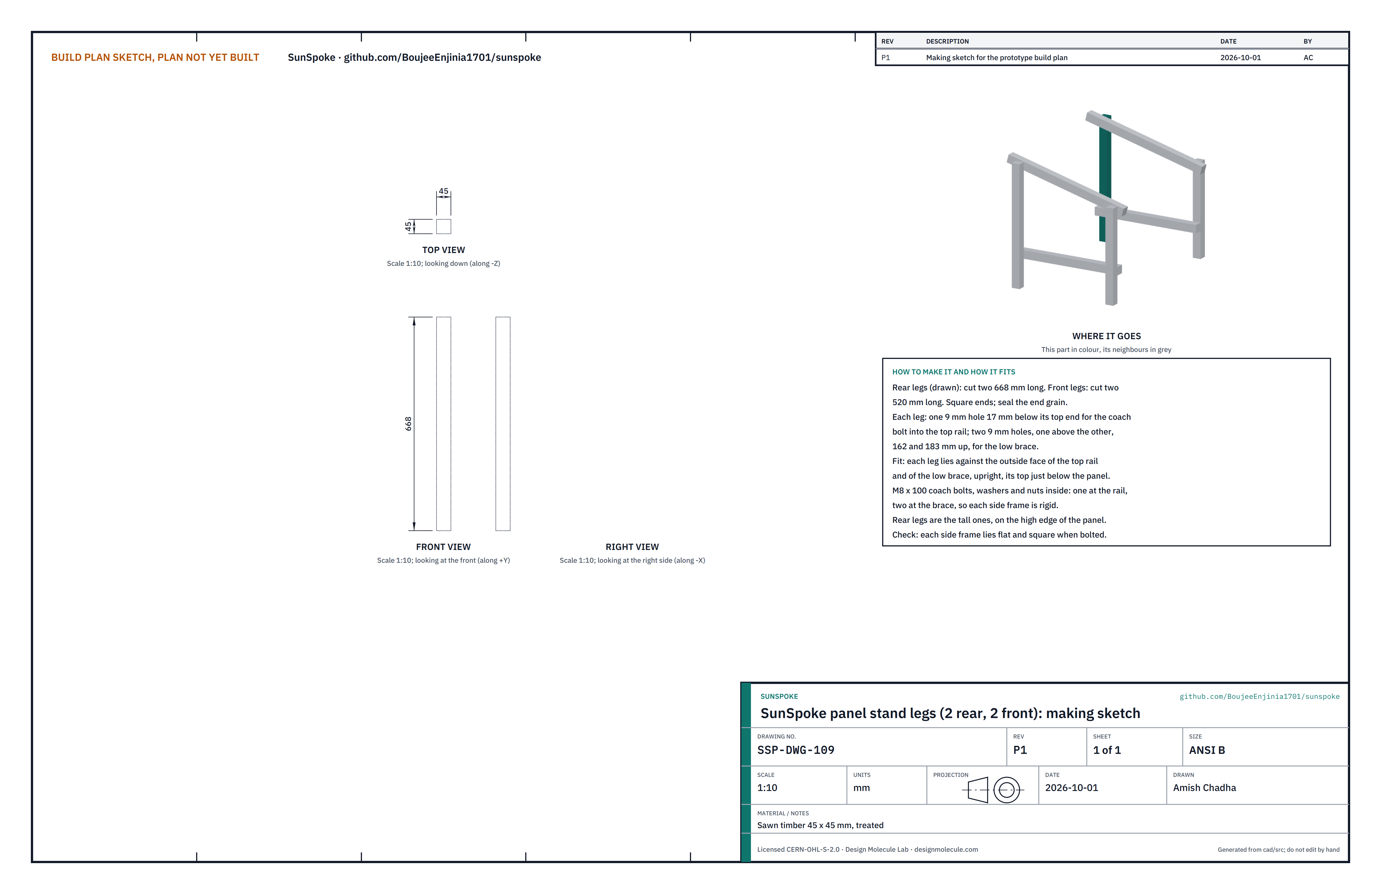
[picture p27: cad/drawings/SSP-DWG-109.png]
Figure 19. Making sketch of the legs


*Figure 19. Legs making sketch (SSP-DWG-109).*

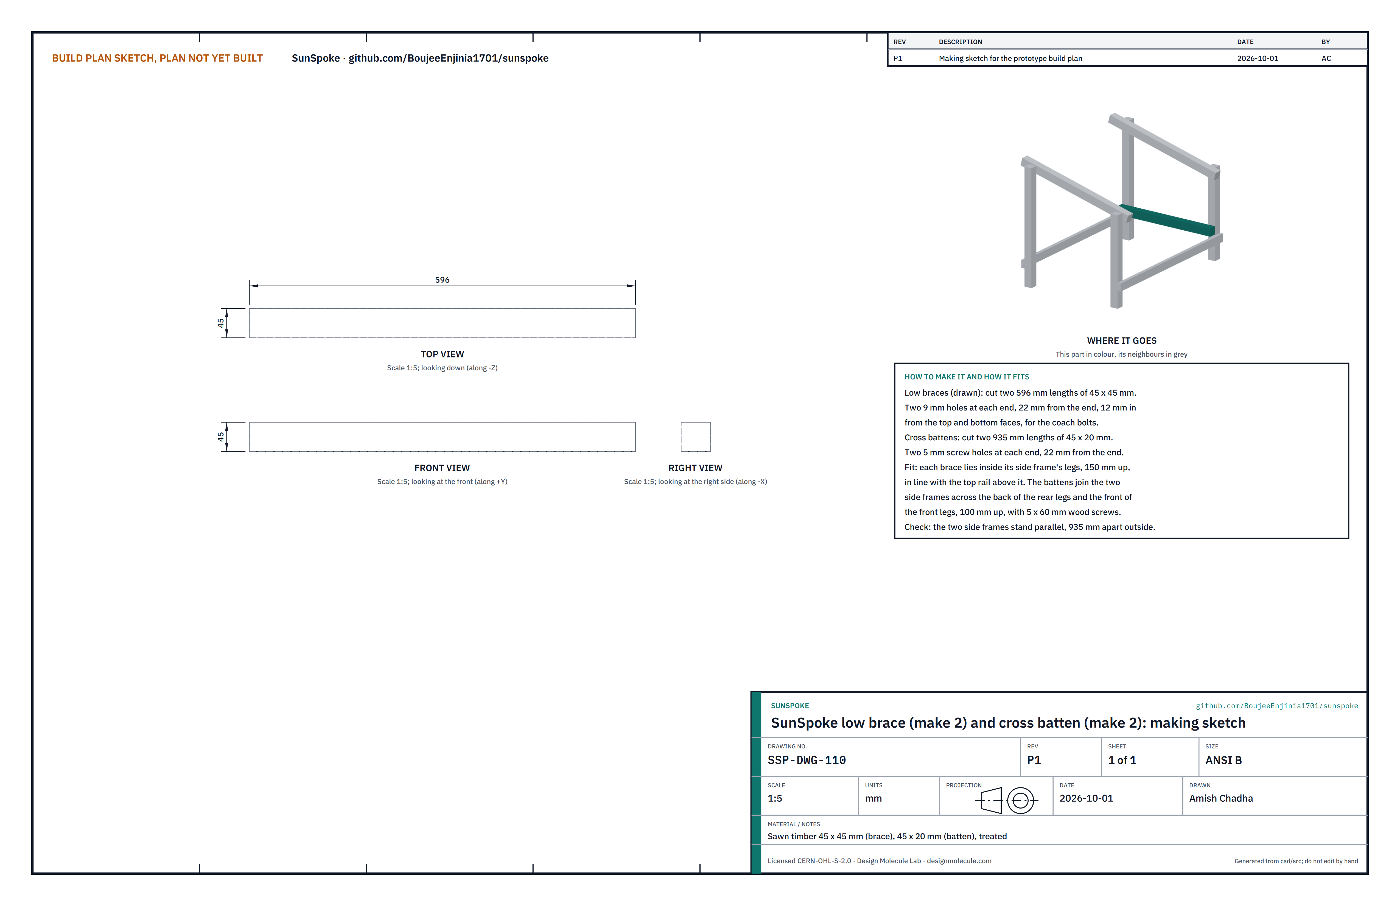
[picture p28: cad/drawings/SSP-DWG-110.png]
Figure 20. Making sketch of the low brace and cross batten


*Figure 20. Low brace and cross batten making sketch (SSP-DWG-110).*

**What it is and what it is made from.** An A-frame that holds the panel at 15 degrees, about 0.5 to 0.7 m off the ground, with the charger in its shade. Treated sawn timber 45 x 45 for the rails, legs and braces, 45 x 20 for the battens; M8 x 100 coach bolts; M6 bolts for the panel; 5 x 60 wood screws.

**How to make it.**

1. Cut two top rails 700, two rear legs 668, two front legs 520, two low braces 596 and two cross battens 935. Seal the end grain.
2. Drill 9 holes for the coach bolts: in each rail, one 15 up from its bottom face at 285 each side of its middle; in each leg, one 17 below its top end and two, one above the other, at 162 and 183 up; in each brace, two at each end, 22 from the end.
3. Drill two 5 holes at each end of each batten, 22 from the end.
4. Lay the panel face down on a soft cloth, set the two rails across its back on its own mounting holes (about 400 each side of its centre line on the long sides), and mark and drill 6.5 holes through the rails to match.

**How it fits the parts next to it.**

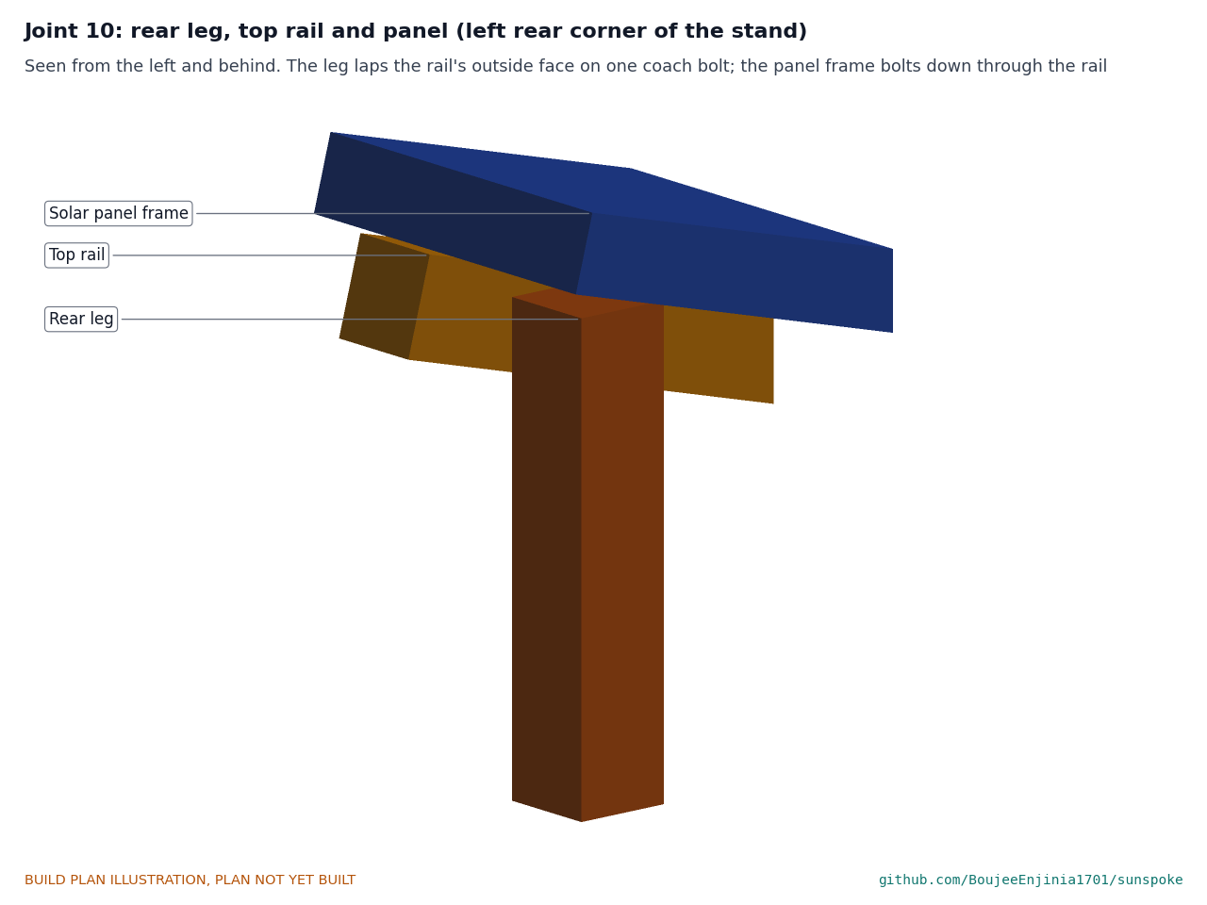
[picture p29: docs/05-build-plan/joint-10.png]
Figure 21. Joint 10: rear leg, top rail and panel


*Figure 21. The leg laps the outside face of the rail on one coach bolt; the panel's frame sits on the rail and bolts down through it.*

Each side frame is a rail and a brace, both inside two legs: one coach bolt where a leg meets the rail, two where it meets the brace, so the frame is a rigid quadrilateral. The rear legs are the tall ones, under the high edge of the panel. The battens join the two side frames across the back of the rear legs and the front of the front legs, 100 up.

**Check before moving on.** Each side frame lies flat and square; the two rails are the same length and drilled alike.

### 3.9 Bought components and what to do to them

Buy to specification, not brand. Line numbers are those of the bill of materials.

- **Motor wheel (line 1).** A 48 V, 250 W geared front hub motor, slow winding, 100 between its locknuts, 10 axle flats on an M12 axle long enough to leave three threads past the nut over a 6 dropout, a 5 arm and a washer; a built-in 10 kΩ winding thermistor. A 28 in (ETRTO 635) steel rim and 13G spokes. The mechanic laces the motor into the rim with a lacing card and fits the donor's tyre and tube.
- **Host adapter and charge inlet (line 5).** As specified in the bill of materials; potted, with two threaded inserts on its base 40 apart, a keyed charge inlet on its left side and a lead to the receptacle.
- **SwapCell receptacle (line 4).** The SwapCell interface v0.3 vehicle receptacle, with its 10 kΩ 1 % INTERLOCK coding resistor and a four-hole flange (37 each side, 24 apart).
- **Hinge and draw latch (line 4).** A stainless butt hinge 60 x 40 open; a stainless over-centre draw latch with an adjustable hook, a keeper and a safety catch, rated 500 N working load or more.
- **Band clamps (lines 4 and 14).** Seven 12 stainless worm-drive band clamps: three for the cradle (about 45 to 60 range), two for the torque arms and two for the controller (each to suit).
- **Fixings (line 14).** Stainless M4 and M5 bolts with nyloc nuts and washers, M4 and M5 countersunk screws, 4 self-tapping screws for plastic, a 4 rubber pad 120 x 40, cable ties, spiral wrap and dielectric grease.

#### 3.9.1 Controller (line 3)

A sealed 48 V, 15 A sine-wave controller with pedal-assist, brake, power-lock, walk-assist and motor thermistor inputs; set by the supplier to a 20 km/h cut-off and a current derate from 110 °C winding temperature.

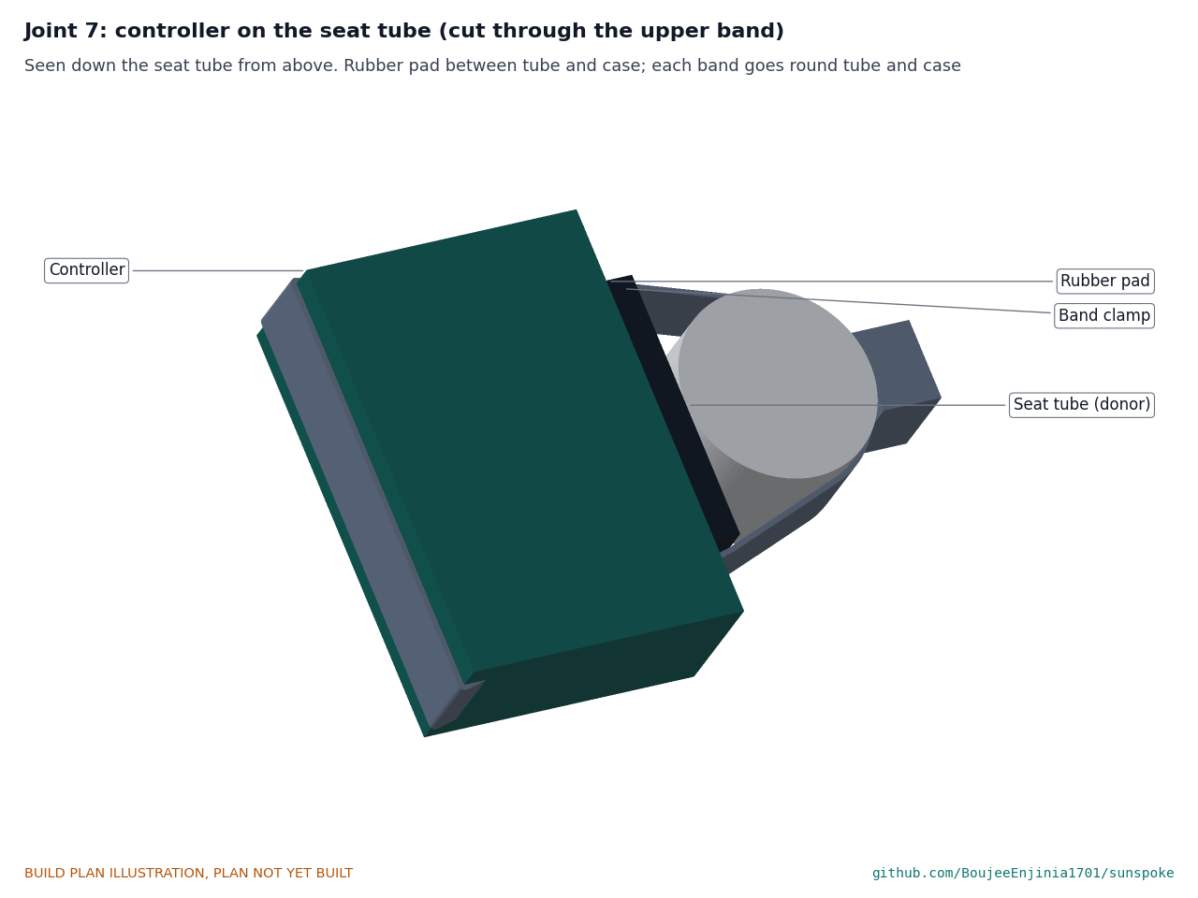
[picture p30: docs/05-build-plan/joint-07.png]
Figure 22. Joint 7: controller on the seat tube


*Figure 22. Cut through the upper band, seen down the seat tube: the rubber pad sits between tube and case, and each band goes round both.*

It sits on the front of the seat tube, about a third of the way up, on the 4 rubber pad, cable glands facing down, held by two band clamps 90 apart.

#### 3.9.2 Pedal-assist sensor (line 7)

A split 12-magnet disc that clamps on the bottom bracket spindle, and a Hall sensor on a thin ring bracket.

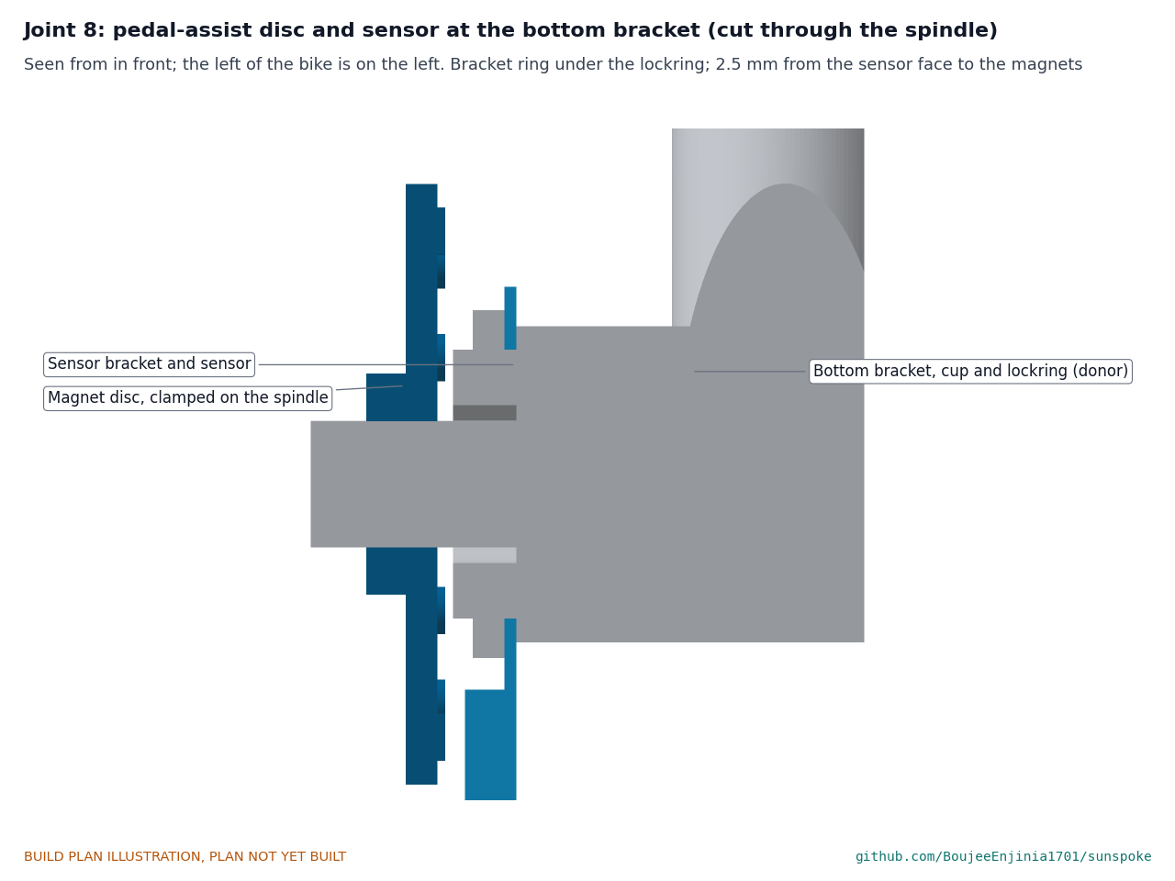
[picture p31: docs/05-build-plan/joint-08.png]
Figure 23. Joint 8: pedal-assist disc and sensor


*Figure 23. Cut through the spindle: the bracket ring sits between the shell and the left lockring; the disc clamps on the spindle 10 outboard of the shell, its magnets 2.5 from the sensor face.*

Take off the left crank. Loosen the left lockring, slip the bracket ring under it with the sensor pointing down, and retighten the lockring while holding the cup still so the bearing adjustment does not change. Clamp the disc on the spindle with its magnets toward the sensor, set a 2 to 3 gap, and refit the crank.

#### 3.9.3 Display and brake sensors (line 8)

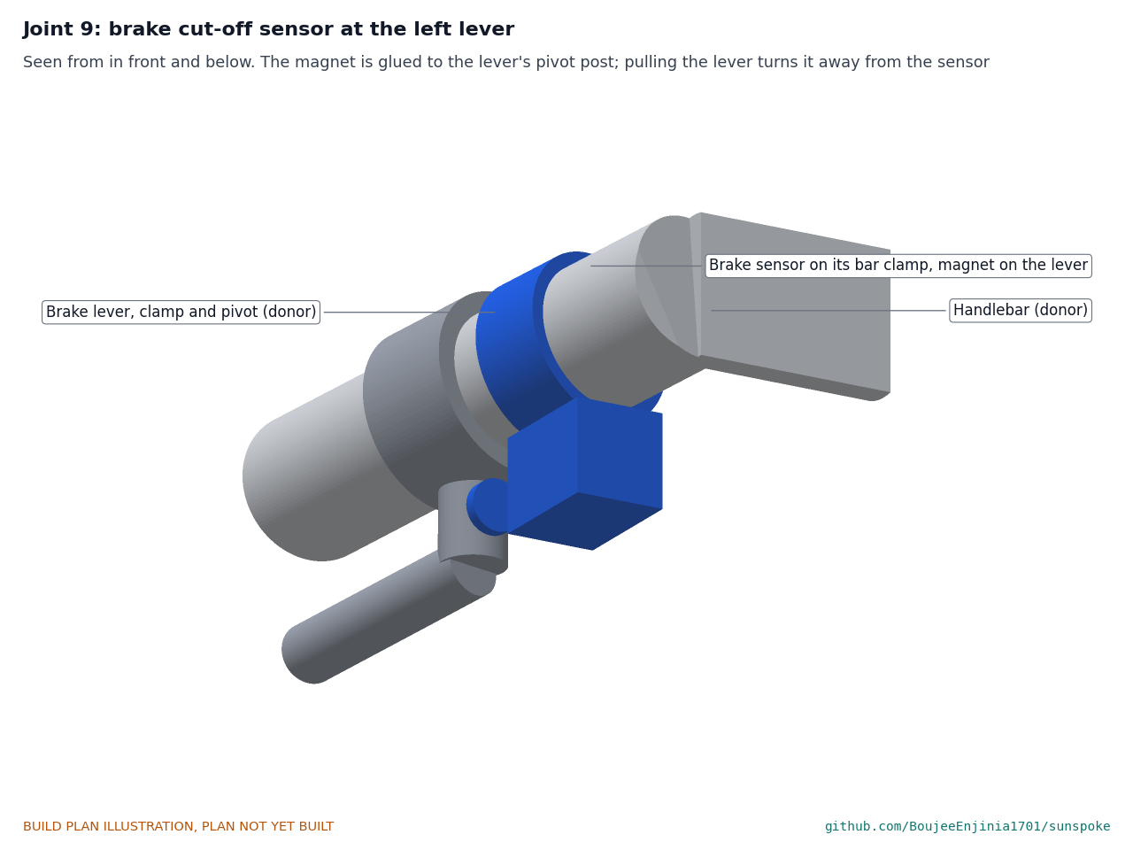
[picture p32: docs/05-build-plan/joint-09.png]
Figure 24. Joint 9: brake cut-off sensor at the left lever


*Figure 24. The sensor clamps on the bar just inboard of the lever's own clamp; its magnet is glued to the lever's pivot post, about 6 from the sensor.*

The display clamps on the bar left of the stem. Each brake sensor clamps on the bar beside its lever; glue its magnet to the lever so that pulling the lever moves the magnet away from the sensor, and check the controller sees the change.

#### 3.9.4 Harness and wiring (line 9)

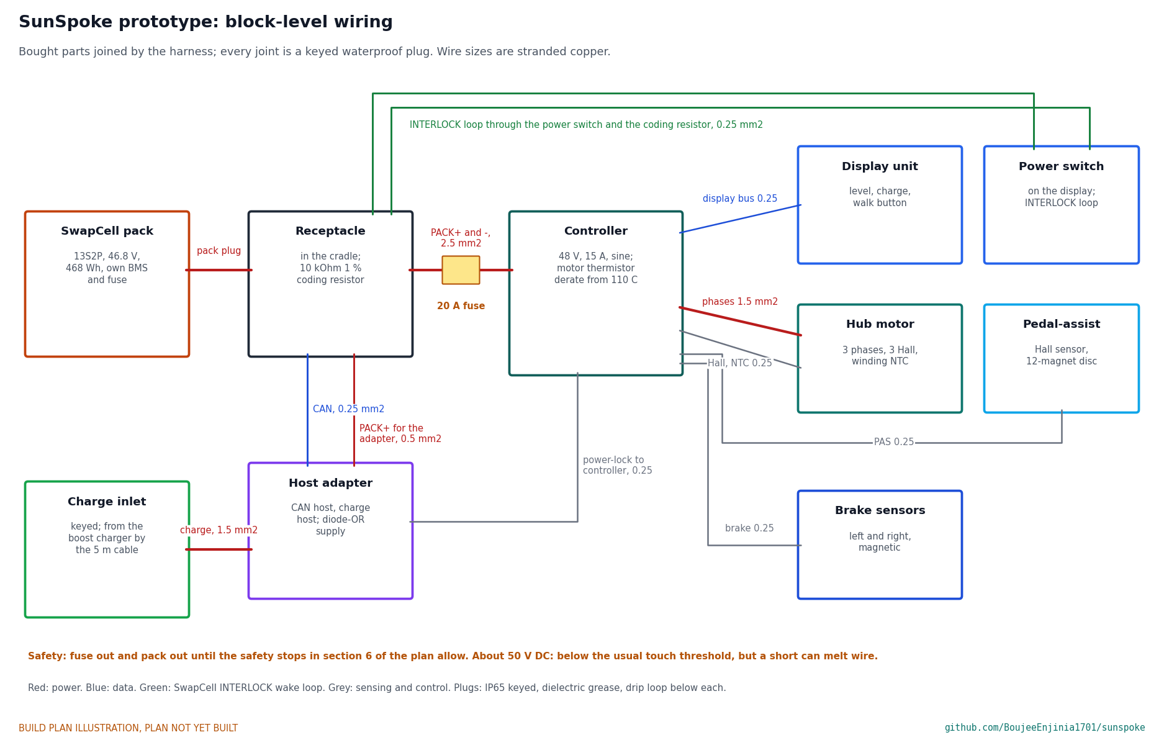
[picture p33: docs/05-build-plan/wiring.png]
Figure 25. Block-level wiring


*Figure 25. Block-level wiring with wire sizes. Every joint is a keyed waterproof plug; no circuit board is laid out at this stage.*

Buy the harness made up to Figure 25, with keyed IP65 plugs, the 20 A fuse in a sealed holder on the pack lead, and spiral wrap. Route it as step 12 shows: from the adapter down the left side of the down tube to the bottom bracket, up the seat tube past the controller, along the left side of the top tube, down the head tube and the front of the left fork blade to the motor's axle, and up the stem to the display and brake sensors. Tie it every 150 and leave a drip loop below every plug.

#### 3.9.5 Solar set (lines 10 to 13)

- **Panel (line 10).** 100 W monocrystalline, about 1,000 x 670 x 35, aluminium frame with mounting holes on its long sides, maximum power voltage about 18 V, with its lead.
- **Charger (line 11).** Boost charger, 15 to 25 V in, constant current and constant voltage to 54.6 V at up to 2 A out, input-voltage tracking, weather-protected case with two mounting ears.
- **Charge cable (line 13).** 5 m of 2-core 1.5 mm² outdoor cable with a keyed plug that fits the host adapter's charge inlet.

#### 3.9.6 Wet-weather brake blocks (line 15)

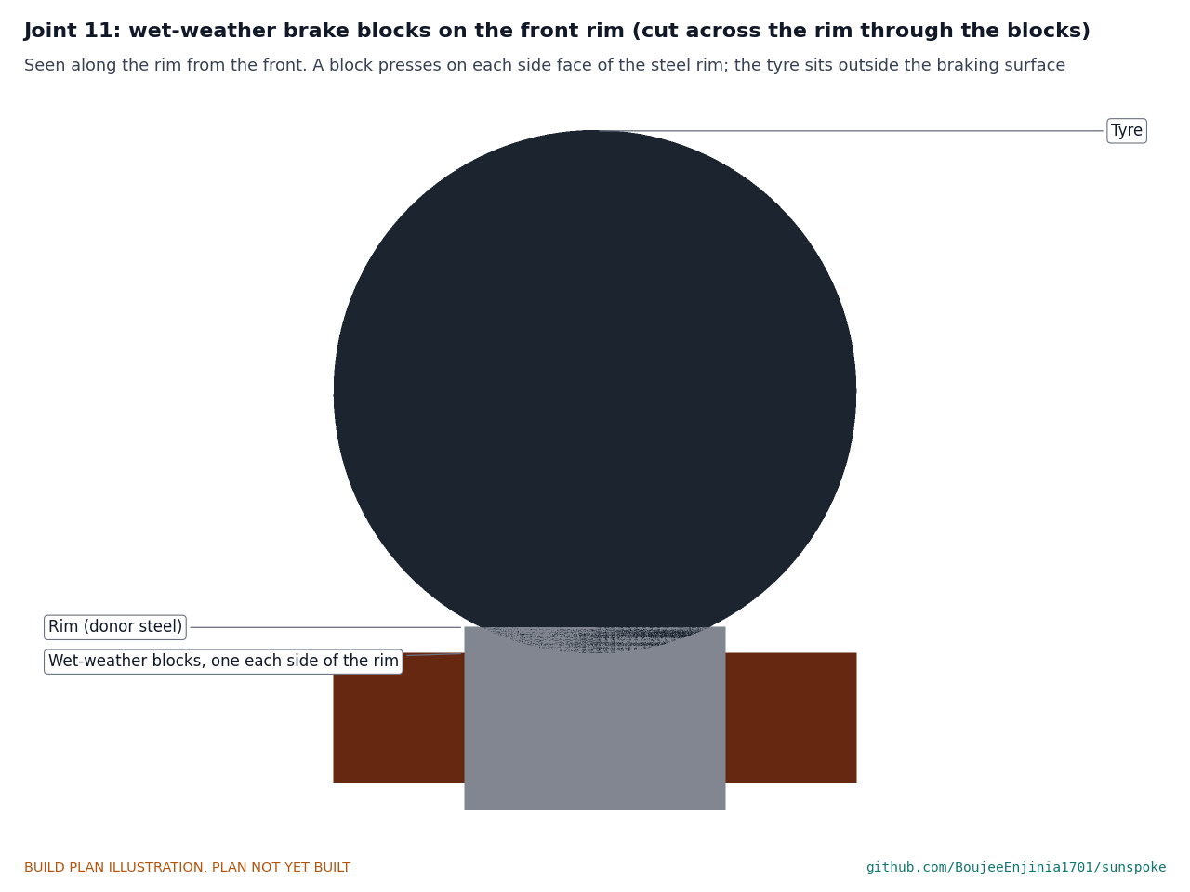
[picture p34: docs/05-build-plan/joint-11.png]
Figure 26. Joint 11: wet-weather brake blocks on the front rim


*Figure 26. Cut across the rim through the blocks: a block presses on each side face of the steel rim, below the tyre.*

Buy two pairs of rubber brake blocks sold for wet-weather use on steel rims, of the donor's block type and fixing so that they fit its stirrups. Each block is about 60 long, 10 thick and 10 deep, and bears on the rim's side face about 310 from the hub. They replace the donor's blocks, so the old ones come off. Fit them as step 11 says and look at each one against its rim before the brake check.

## 4. Putting it together

In each picture the parts already fitted are grey and the part being fitted is in colour, with an arrow showing the way it goes in. Steps 1 to 4 are on the bench; steps 5 to 13 on the bike; steps 14 to 16 build the solar set.

### Step 1: V-saddles onto the tray

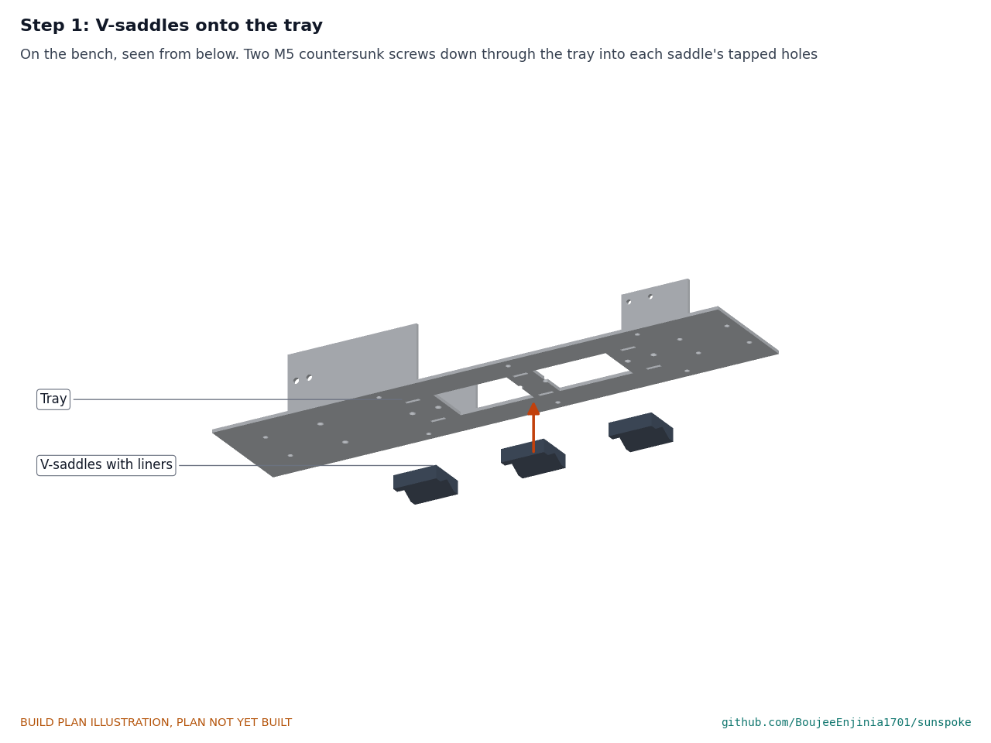
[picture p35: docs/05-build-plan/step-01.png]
Step 1


Two M5 countersunk screws down through the tray into each saddle, V downward, saddles centred under the three slot pairs.

### Step 2: slide strips, catch bar, end stop and receptacle

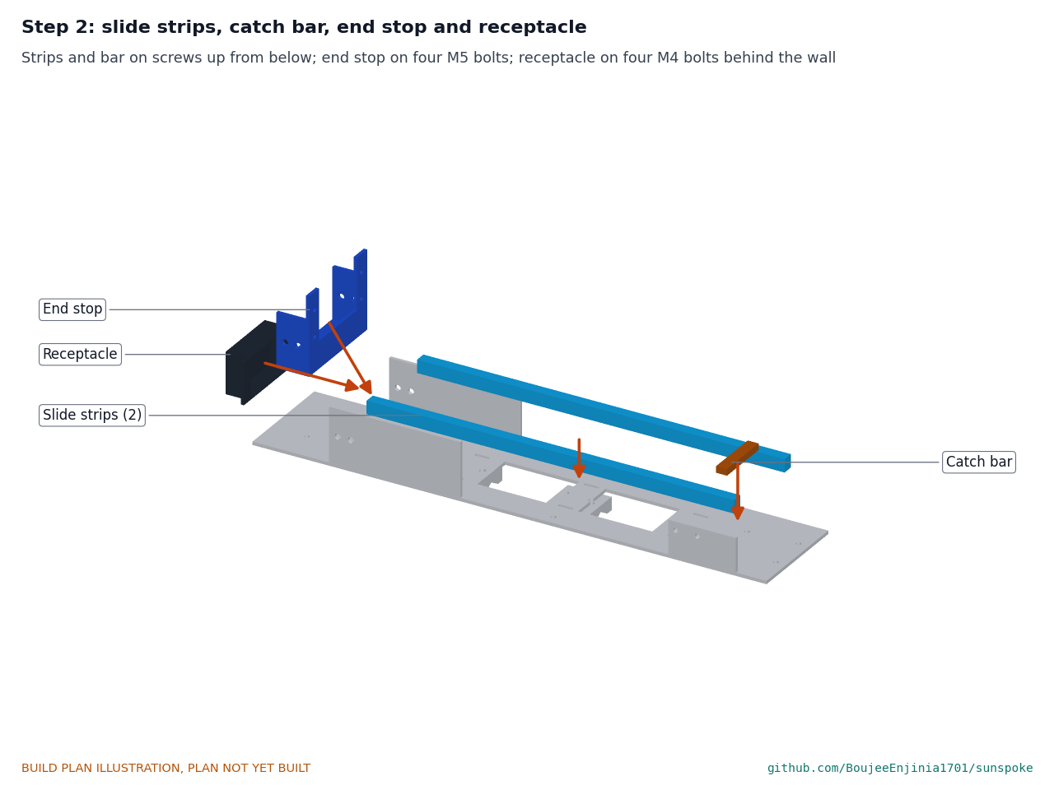
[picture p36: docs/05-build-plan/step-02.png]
Step 2


Strips on three plastic screws each and the catch bar on two M4 countersunk screws, all up from below. End stop between the guides on four M5 bolts in its flanges and two in its foot, nyloc nuts. Receptacle behind the wall on four M4 bolts.

### Step 3: gate, hinge and draw latch

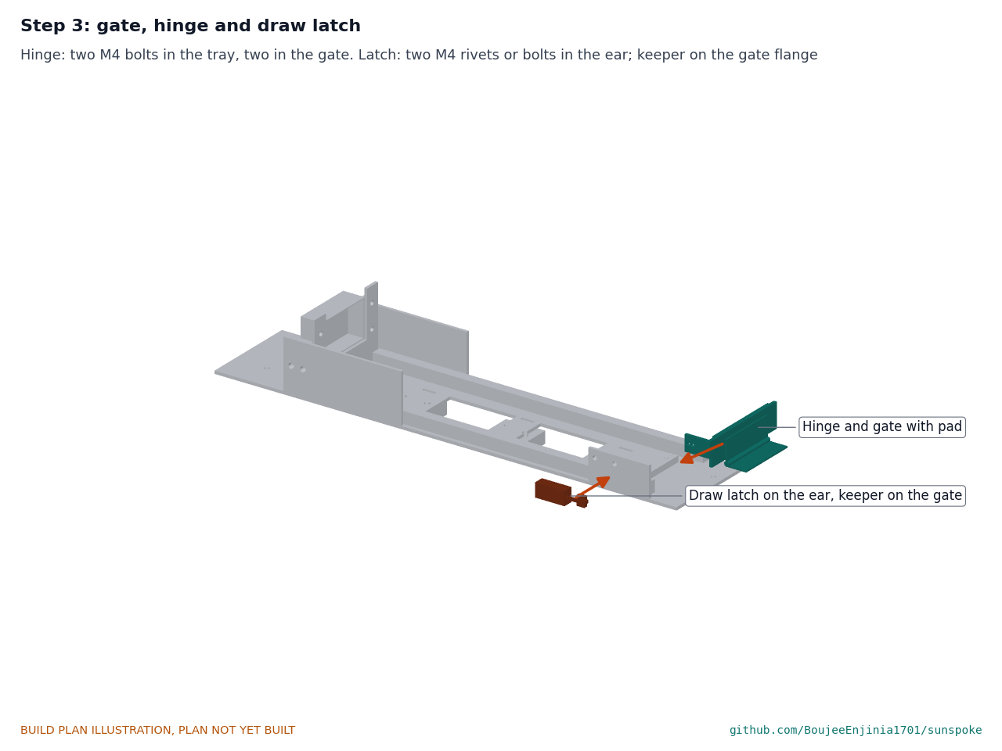
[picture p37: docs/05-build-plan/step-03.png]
Step 3


Hinge to the tray and the gate on M4 bolts with nyloc nuts. Latch on the outside of the ear, its hook toward the gate, on two M4 rivets or bolts. Check the gate folds flat and closes.

### Step 4: host adapter and its lead

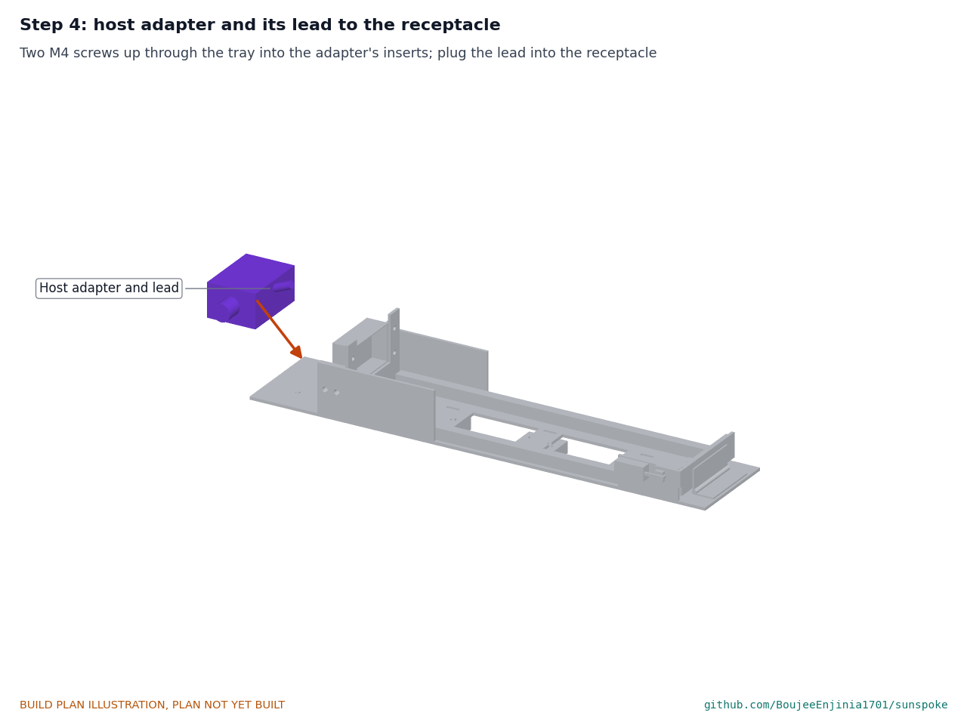
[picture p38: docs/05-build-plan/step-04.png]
Step 4


Two M4 screws up through the tray into the adapter's inserts. Plug its lead into the receptacle and tie it to the end stop.

### Step 5: cradle onto the down tube

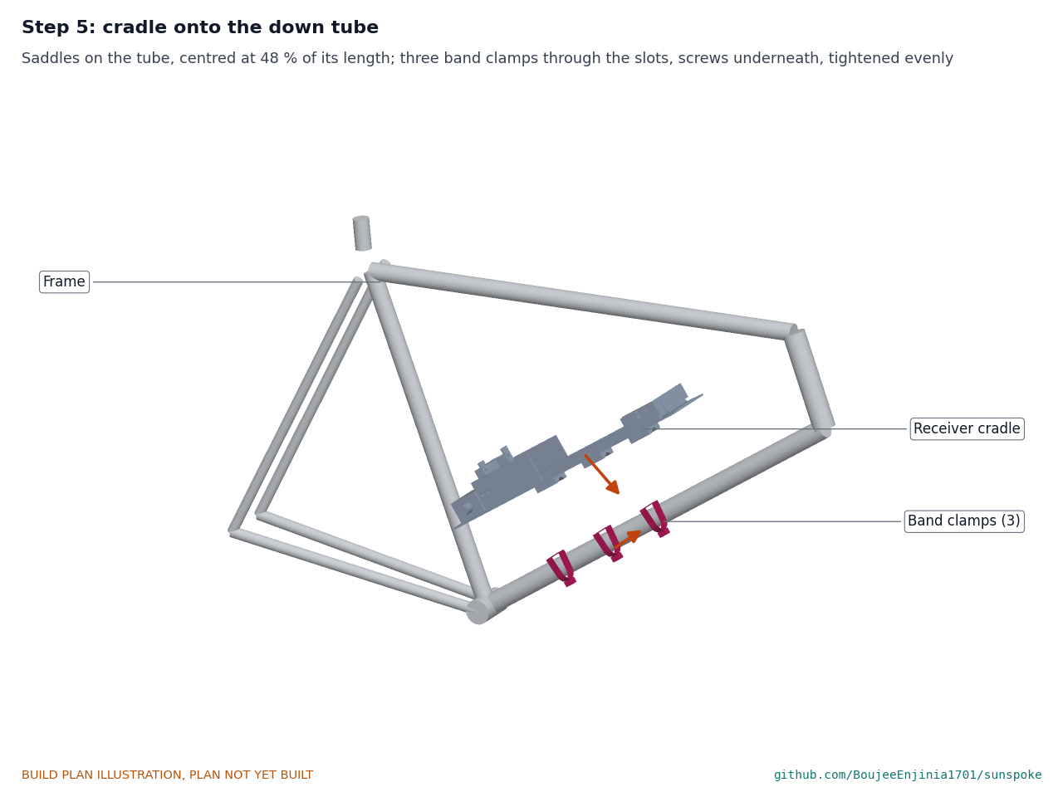
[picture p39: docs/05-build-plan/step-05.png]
Step 5


Mark a point 48 % of the way up the down tube from the bottom bracket (346 on a 721 tube). Set the cradle on the tube, middle saddle on the mark, guides toward the bottom bracket, ear on the left. Thread each band down through its slots and round the tube, screw underneath. Tighten the three bands evenly to the clamp maker's torque (typically 3 to 4 N·m) and record it. **Hold point:** the cradle does not turn on the tube when pushed hard by hand at the end stop.

### Step 6: motor wheel and torque arms into the fork

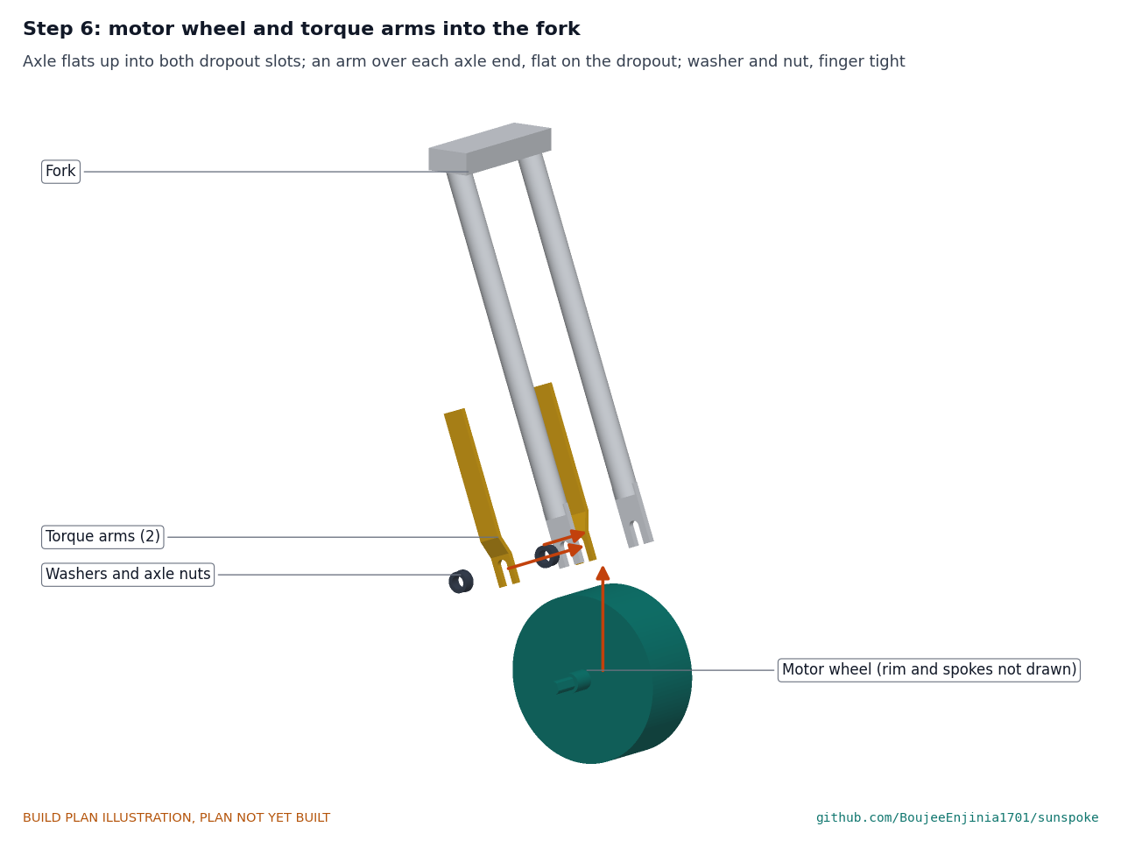
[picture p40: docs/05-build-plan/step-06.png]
Step 6


With the bike on a stand, lower the fork over the motor wheel so the axle flats slide up both dropout slots, cable on the left. Slip a torque arm over each axle end, slotted end flat on the dropout, long end up the outside of the blade. Washer and nut on each side, finger tight.

### Step 7: torque arm band clamps, then the axle nuts

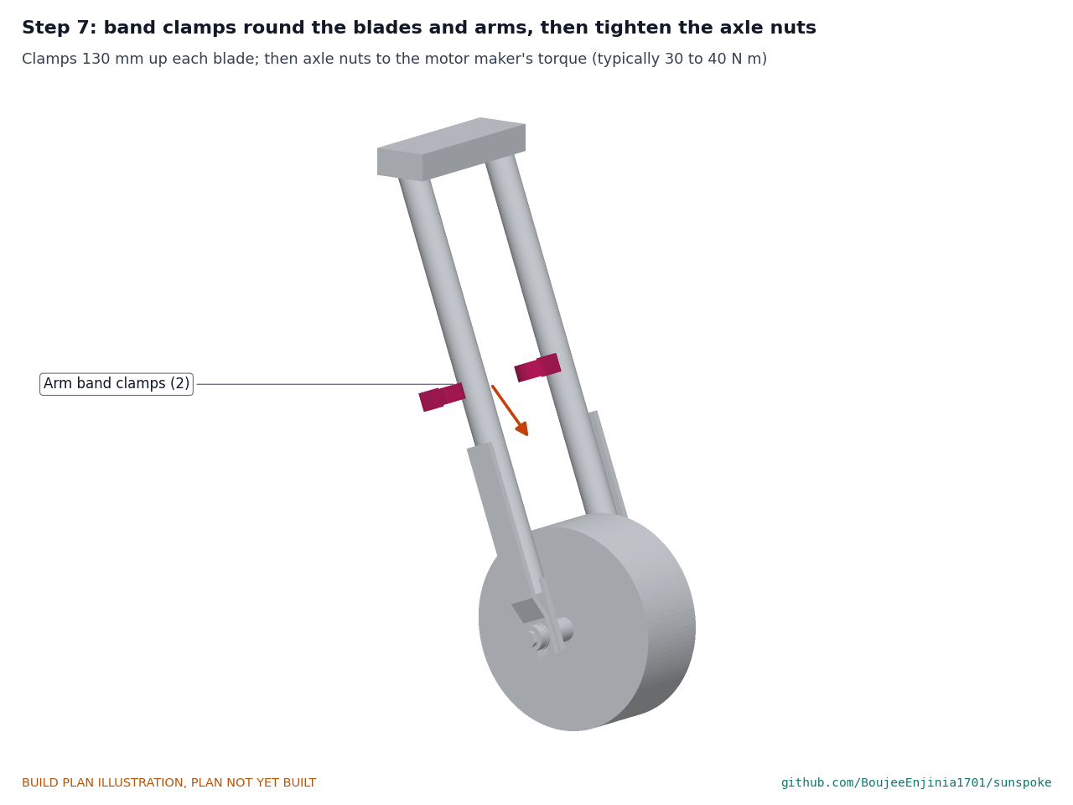
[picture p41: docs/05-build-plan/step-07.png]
Step 7


A band clamp round each blade and arm, 130 up from the axle, snug. Centre the wheel in the fork, then tighten the axle nuts to the motor maker's torque (typically 30 to 40 N·m) and the arm clamps to the clamp maker's torque. **Hold point:** safety stop S2.

### Step 8: controller onto the seat tube

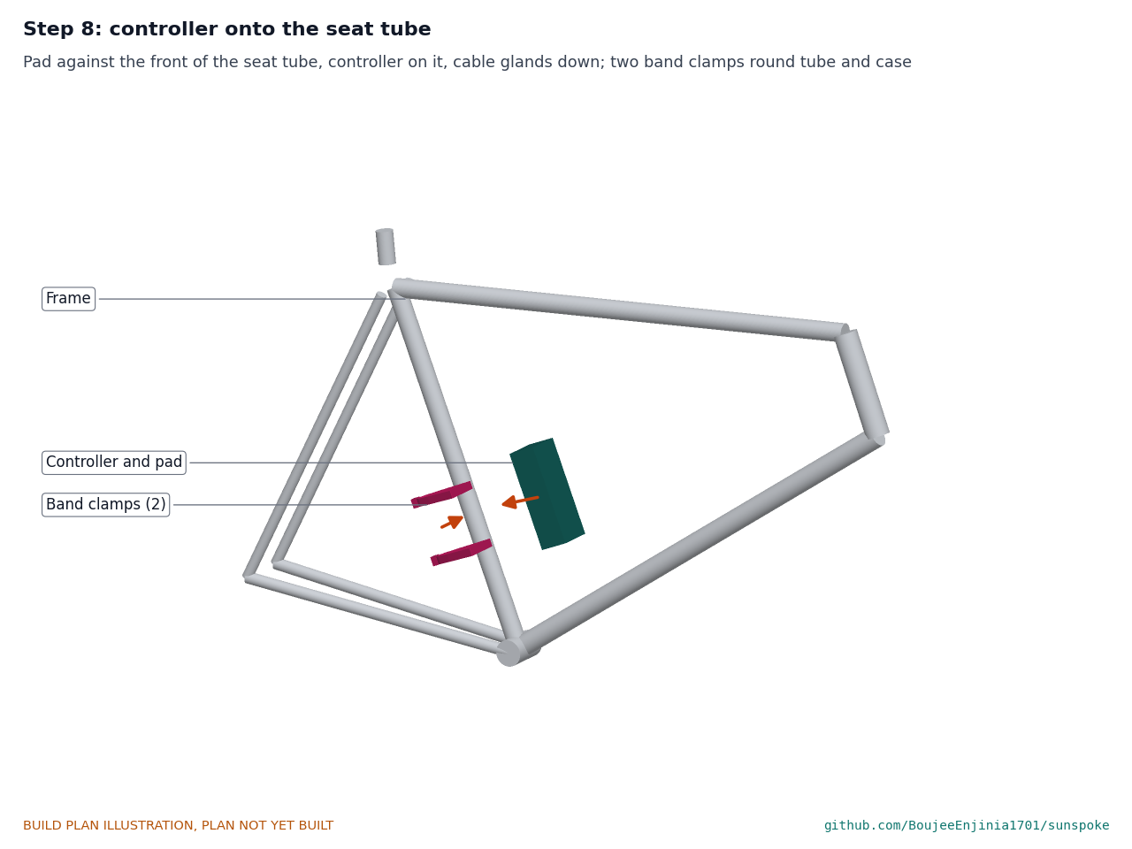
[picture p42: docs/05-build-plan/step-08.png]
Step 8


Rubber pad on the front of the seat tube, controller on it, glands down; two band clamps round tube and case.

### Step 9: pedal-assist sensor and disc

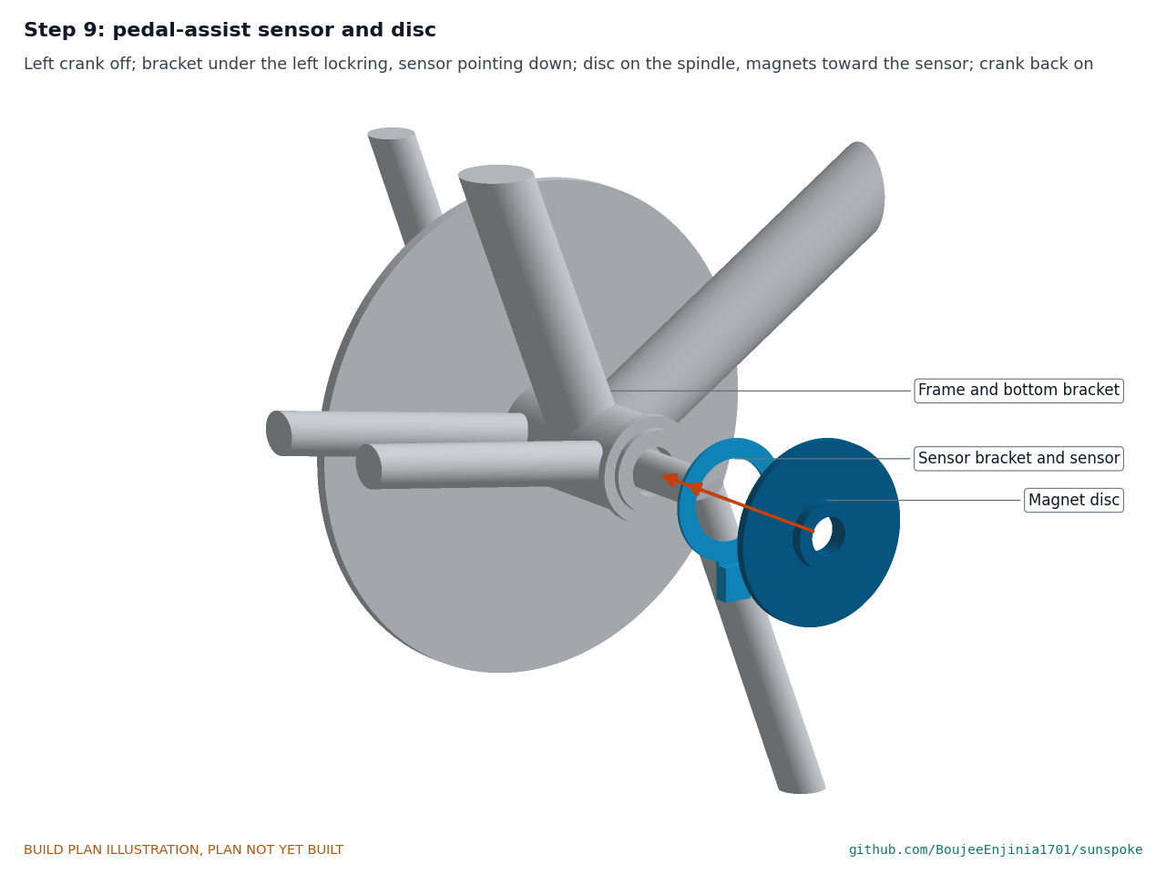
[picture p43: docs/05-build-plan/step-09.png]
Step 9


Left crank off; bracket under the left lockring, sensor pointing down; lockring tight with the cup held; disc on the spindle with a 2 to 3 gap to the sensor; crank back on and tight.

### Step 10: display and brake sensors

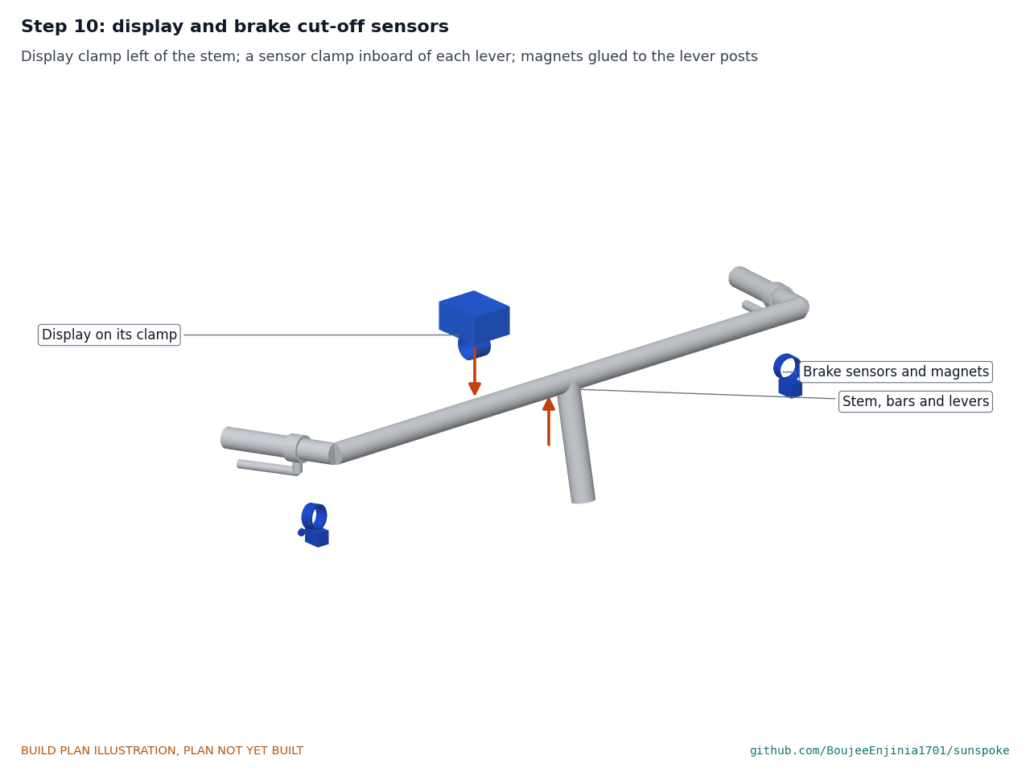
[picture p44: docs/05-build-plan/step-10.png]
Step 10


Display left of the stem, angled so the rider can read it. A sensor beside each lever, magnet glued on the lever.

### Step 11: wet-weather brake blocks

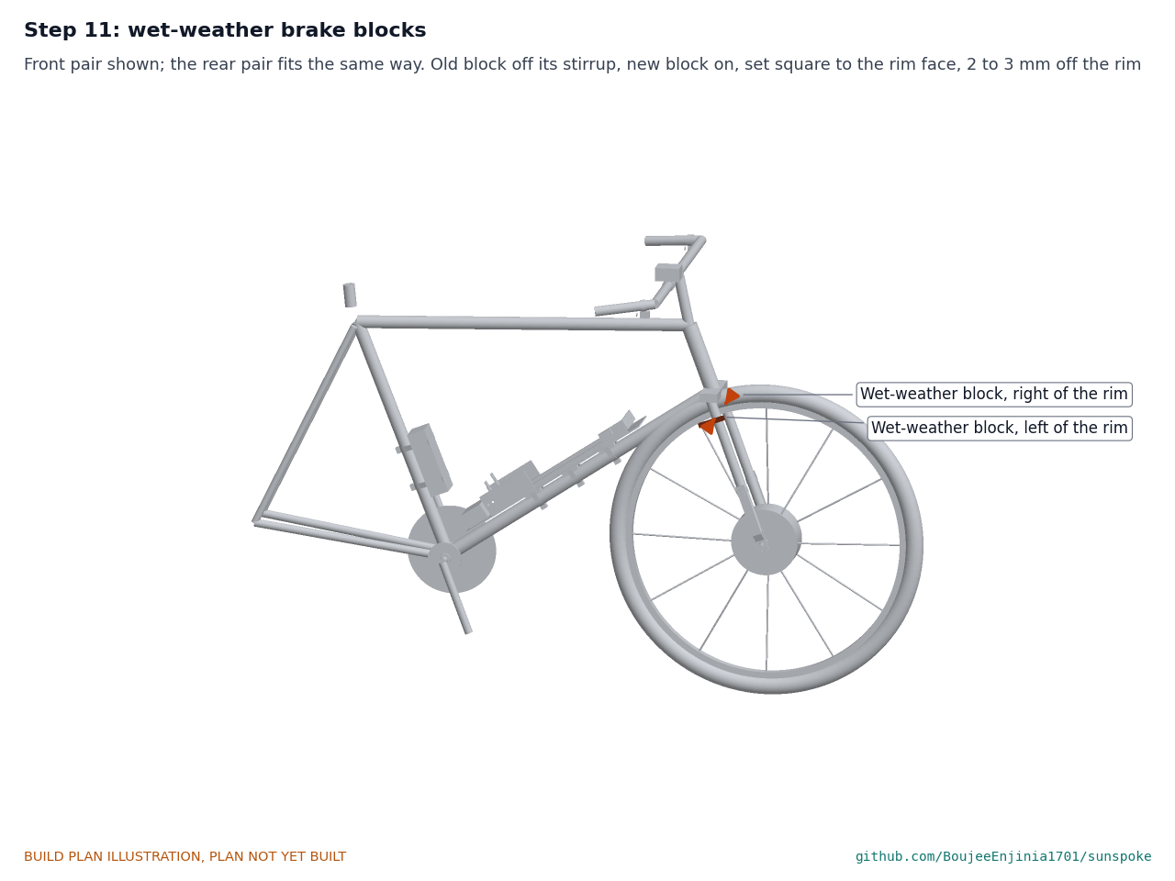
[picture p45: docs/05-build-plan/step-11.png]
Step 11


Take the donor's old block off each brake stirrup, front and rear, and fit a wet-weather block in its place, so four blocks in all. Set each block square to the rim's side face, level with the middle of the braking surface and 2 to 3 off the rim when the brake is released. Only the front pair is drawn; the rear pair fits the same way. Section 3.9.6 gives the block and how to set it.

### Step 12: harness

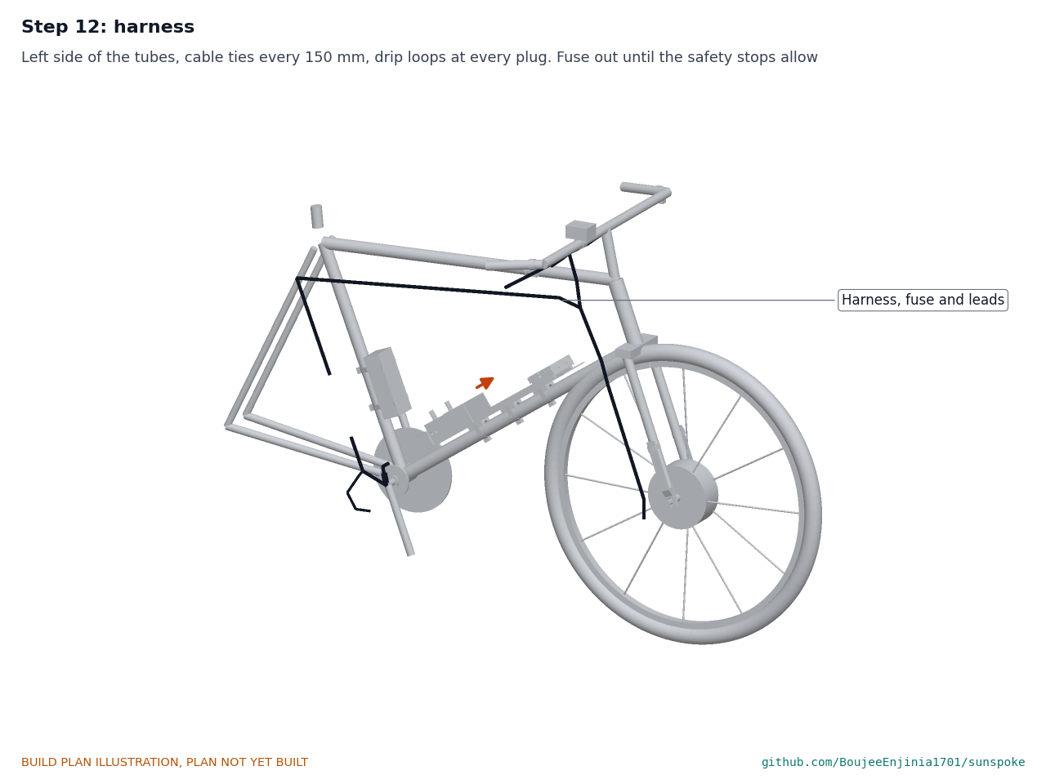
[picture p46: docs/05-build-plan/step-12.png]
Step 12


Route the harness as section 3.9.4 says, plug every joint with dielectric grease, and tie it every 150. Leave the fuse out. **Hold point:** safety stop S3.

### Step 13: pack in, gate up, latch closed

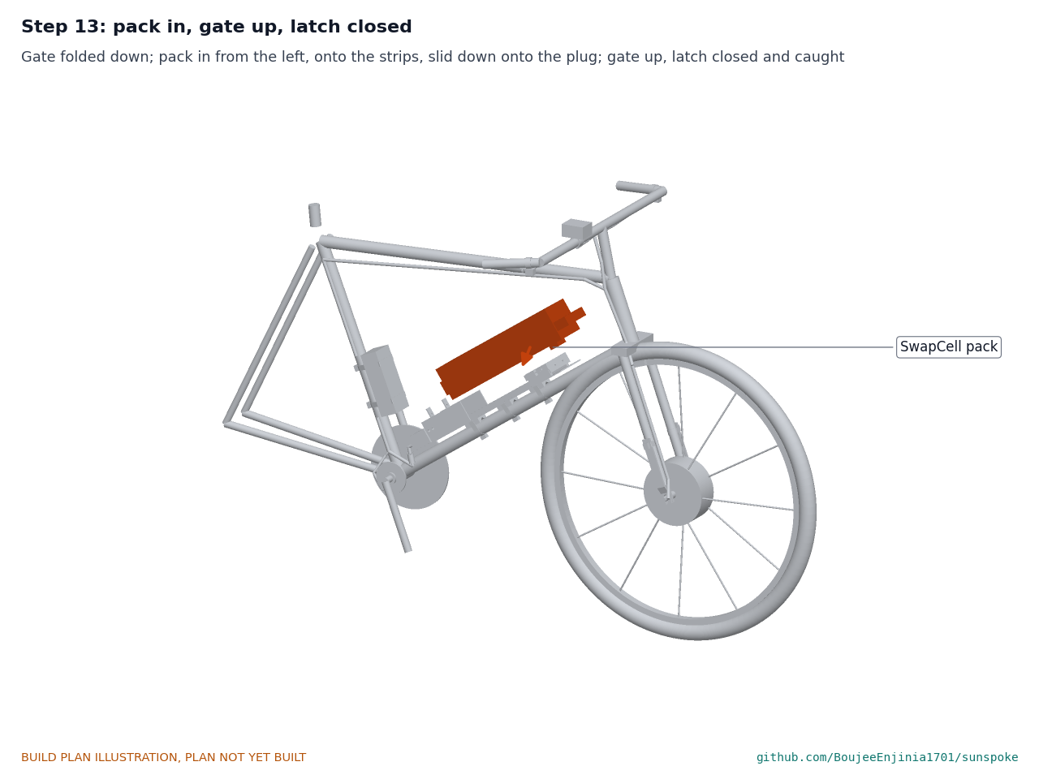
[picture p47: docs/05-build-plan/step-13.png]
Step 13


Only at safety stop S4. Fold the gate down. Hold the pack by its handle, set it on the strips from the left about 145 up from the end stop, and slide it down onto the plug until it seats on the wall and its latch drops behind the catch bar. Raise the gate, close the draw latch over centre and flip its safety catch. To take the pack out: catch off, latch open, gate down, press the pack's latch release, slide it 145 up the tube by its handle, lift it 45 off the strips and take it out to the left.

### Step 14: the stand's two side frames

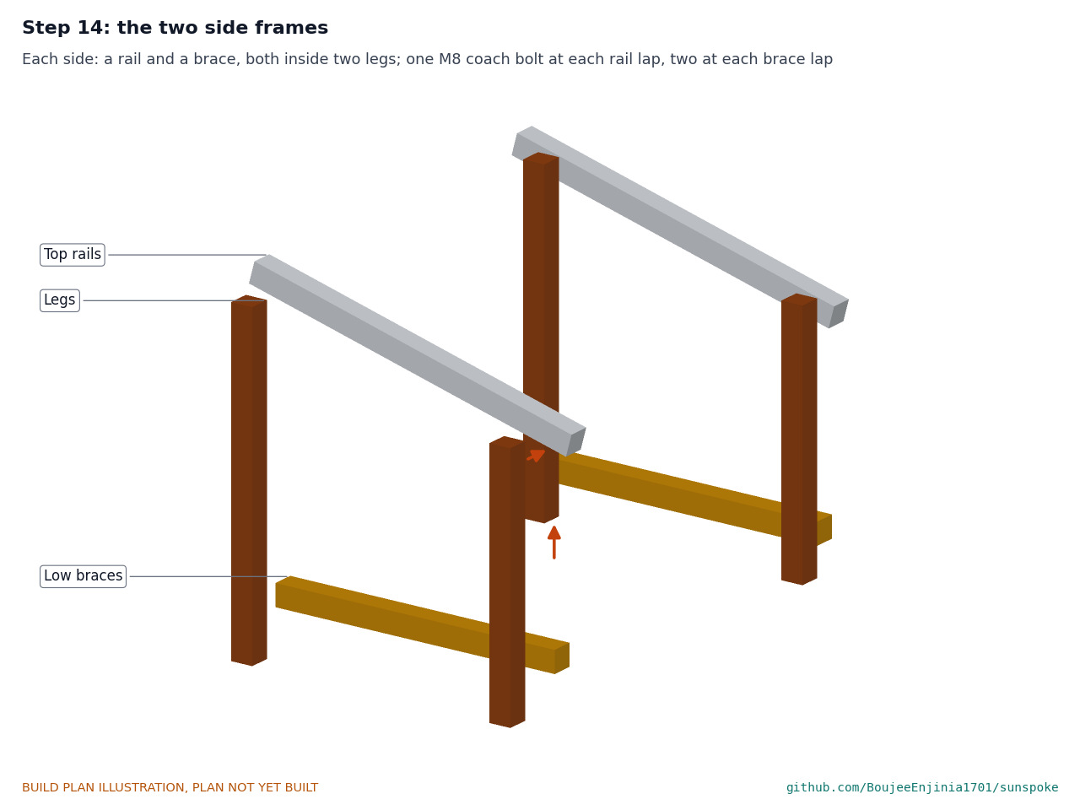
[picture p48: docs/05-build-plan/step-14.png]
Step 14


Each side: a top rail and a low brace inside two legs, the tall rear leg under the high end. One coach bolt at each rail lap and two at each brace lap, washers and nuts on the inside.

### Step 15: battens, then the panel

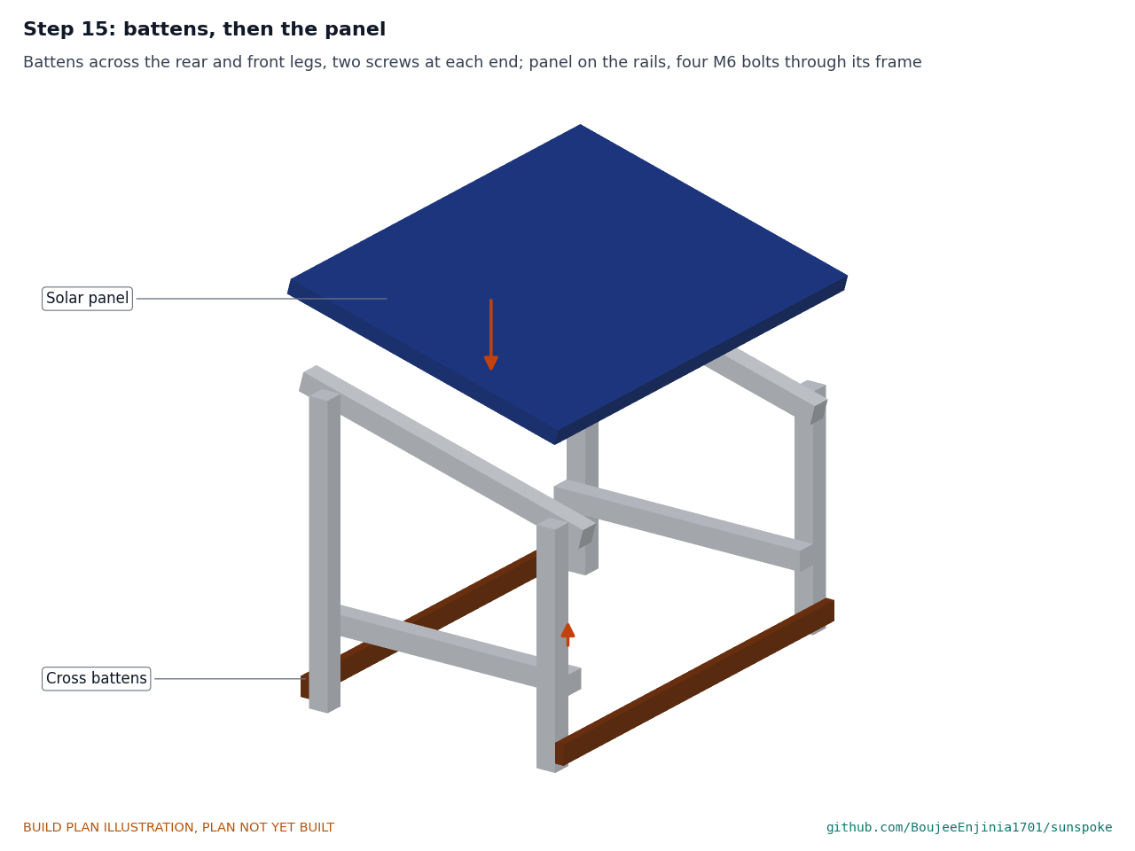
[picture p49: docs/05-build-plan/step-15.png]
Step 15


Stand the side frames 935 apart outside and screw the battens across the back of the rear legs and the front of the front legs. Lay the panel on the rails, glass up, and bolt it down through its frame holes with four M6 bolts, washers and nuts.

### Step 16: charger and panel lead

Step 16

Screw the charger to the outside of the left rear leg, in the panel's shade. Plug the panel lead into its input and tie it to the rail. The 5 m charge cable runs from the charger to the bike's charge inlet only at safety stop S6.

## 5. First checks

These are the checks a TRL 4 test report would record; this plan only lists them. Requirement numbers are those of SSP-REQ-001.

*Table 2. First checks.*

| Check | Requirement | How | Pass when |
| --- | --- | --- | --- |
| No work on the donor | R4 | Look over the frame and fork after fitting | No weld, hole, cut or filing on frame or fork |
| Fitting time | R4 | Time a trained mechanic fitting a second kit with the parts made | 90 min or less |
| Fit to the donor | R5 | Saddles, dropouts, bottom bracket and levers as section 1 | Every part seats as its joint picture shows |
| Cradle grip | R13 | Push hard by hand at the end stop and sideways at the top end | No movement of the cradle on the tube |
| Pack seating and preload | R13 | Seat the pack and close the latch; pull the gate open at the pad with a spring balance | Latch goes over centre with 50 N or less at its lever; the gate does not lift off the pack below 330 N; safety catch engages |
| Pack swap | R13 | Take the pack out and put it back as step 13 | No tools needed and nothing catches; time recorded |
| Torque arms | R10 | Check both arms are keyed and clamped; wheel turns freely | No shake on the flats; clamps at torque |
| Fuse and wiring | R9, R10 | Pack out, fuse out: meter every plug to frame | Open circuit to the frame everywhere |
| Wake and power switch | R10, R13 | Pack in, fuse in, switch on and off | The pack wakes with the switch on and its output opens with it off |
| Wet-weather blocks | R11 | Look at each block against its rim with the brake released and applied | All four blocks bear flat on the rim's side face, 2 to 3 off it when released, and clear of the tyre |
| Brake cut-off | R10 | Wheel off the ground, gentle assist, pull each brake lever | Motor stops within 0.5 s on either lever |
| Assist settings | R1 | Read the controller settings | 20 km/h cut-off, walk assist 6 km/h, no throttle |
| Charging | R8, R13 | Panel in sun, charge cable to the inlet, bike off then on | Charger output flows into the pack; mode 3 with the bike off, mode 4 with it on |
| Mass | R6 | Weigh the bike before and after, with the pack | 7 kg or less added (6.88 kg estimated) |
| Stand | | Push on the panel corners by hand | Nothing moves at any joint |

## 6. Safety stops

Stop at each point. Carry on only when everything listed is true.

- **S1. Before the pack comes near the workshop.** It is a SwapCell pack from that project, undamaged, not swollen and never submerged, at a storage charge. A charging place is ready on a non-combustible surface, in shade and away from sleeping areas, with a fire extinguisher for electrical fires and a sand bucket within reach.
- **S2. Before the bike is ridden or the motor turned under power (after step 7).** Both torque arms keyed on the flats and clamped; axle nuts at the motor maker's torque; the fork and dropouts uncracked and unfiled.
- **S3. Before the fuse goes in (after step 12).** Pack out. Every plug fully home and greased; no cable crossing a moving part (wheel, cranks, steering lock to lock); every lead meters open to the frame; the fuse is 20 A.
- **S4. Before the pack goes in (step 13).** Fuse in; power switch off; brake sensors and their magnets fitted; all four wet-weather blocks fitted; the wheel off the ground or the bike on a stand.
- **S5. Before any powered test.** Gate closed with the latch over centre and its safety catch on; cradle bands at torque; the bike on a stand with the front wheel clear of the ground; brakes adjusted with the wet-weather blocks of step 11.
- **S6. Before any charging.** The charging place of S1; the charger's output set and measured at 54.6 V or less with nothing connected; the panel lead and charge cable polarity checked with a meter; never charge a pack that is hot, damaged or below 0 °C; attended throughout the first charge.
- **S7. Before anyone rides it (outside this plan).** No trial is ridden in the wet until a wet braking test with the wet-weather blocks meets R11's wet target (SSP-DEC-001). First rides are TRL 4 tests on a closed, dry site, at walking pace first, by a rider with a helmet, after the brake cut-off and stopping checks pass. Rod brakes on steel rims stop poorly in the wet: no wet riding.

## 7. Tools, skills and workspace

**Tools.** Hacksaw with a 24 teeth per inch blade; jigsaw with metal and wood blades; aviation snips; bench vice with soft jaws and two lengths of steel angle for folding; bench drill or a drill in a stand; drills 3 to 9 mm; countersink; M4 and M5 taps and tap drills; flat and half-round files; deburring tool; scriber, square, protractor, steel rule and calipers; a 10 mm gauge (or a 10 mm drill shank); screwdrivers and a nut driver for band clamps; spanners to 19 mm and hex keys; torque wrench to 40 N·m and a torque screwdriver to 6 N·m; crank puller and bottom bracket lockring spanner; spoke key and a truing stand or the fork itself; wood saw, 9 mm wood drill, socket for coach bolts; multimeter; contact adhesive; scale to 50 kg (weigh the bike in a sling); stopwatch.

**Skills.** A trained bicycle mechanic for the wheel build, bottom bracket, brakes and fitting; basic metalwork (marking out, sawing, drilling, tapping, folding sheet) for the cradle and torque arms; basic carpentry for the stand. Plug-together wiring only: no soldering on the bike. Care with lithium-ion packs as section 6 says.

**Workspace.** A bench about 1.5 x 0.6 m with a vice; a bike stand; a metalwork corner kept apart from the electrics so chips stay off the plugs; an outdoor spot for the solar set; the charging place of S1.

**Personal protective equipment.** Safety glasses for cutting, drilling and folding; cut-resistant gloves for sheet and bar; hearing protection when sawing; no gloves near a turning drill.

## 8. Where the numbers come from

- Model and constructability checks: `cad/src/model.py` (`python cad/src/model.py --check`, 59 checks); STEP and STL exports in `cad/step/` and `cad/stl/`.
- Pictures: `cad/src/build_plan_media.py`, using `.kit/build_views.py`; written to `docs/05-build-plan/` and `cad/drawings/SSP-DWG-101` to `SSP-DWG-110`.
- General arrangement: `cad/drawings/SSP-DWG-001.pdf`, Rev P4.
- Calculations: `docs/04-calcs/01-sizing.md` (SSP-CAL-001 v0.5) and `docs/04-calcs/sizing.py`; mass (section 2), torque arms (section 7), cradle retention, gate and end stop (section 8), fit and removal path (section 9).
- Bill of materials: `bom/bom.csv`.
- Decisions: `docs/decisions/0003-design-for-construction.md` (SSP-DDR-003), with SSP-DDR-001 and SSP-DDR-002; open items in `docs/06-design-decisions.md` (SSP-DEC-001).
- Requirements: `docs/03-requirements.md` (SSP-REQ-001 v0.7).

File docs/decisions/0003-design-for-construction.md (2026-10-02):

---
doc_id: SSP-DDR-003
title: SunSpoke design for construction
project: SunSpoke
doc_type: Design decision record
version: "0.2"
status: Draft
date: '2026-10-02'
author: Amish Chadha
license: CERN-OHL-S-2.0
revisions:
- version: "0.1"
  date: '2026-10-01'
  author: Amish Chadha
  change: Changes that make the concept physically buildable, with the reason for each; made under Amish's 2026-09-30 instruction to make the design physically buildable; open for his review
- version: "0.2"
  date: '2026-10-02'
  author: Amish Chadha
  change: "Accepted by Amish on 2026-10-02, with A1 and A2 as recommended"
---

# 0003: Design for construction

- **Date:** 2026-10-01
- **Status:** accepted. Amish, 2026-10-02: "i approve your recommendations for all 555 open decisions." This covers every change in Table 1 (P1 to P13) and the items in Table 3 (A1 and A2), now decided as recommended and recorded in the design decisions register (SSP-DEC-001).

## Context

On 2026-09-30 Amish asked for every repo to have an illustrated build plan and wrote: "If you are realising that the design cannot be built as per concept - fix the design assumptions to match and be physically feasible as you draw the illustrations." The TRL 3 model of SunSpoke (SSP-DDR-001, SSP-DDR-002) was a massing model with correct interfaces. Checking it part by part with build123d showed that many kit parts overlapped their neighbours, floated with no fixing, or could not be made as drawn, and that the pack could not be taken out of the cradle because the lever's hinge block stood in its path.

The changes keep what SunSpoke does: the same 250 W front hub motor, 48 V SwapCell pack on the down tube at the same place, the same controller, sensors, display, harness, charging route and solar set; no welding, drilling or cutting of the donor frame or fork; SwapCell interface v0.3 items W, C and V; and the same safety case. Every change is in `cad/src/model.py`, which now runs 57 constructability checks (`python cad/src/model.py --check`): parts that must touch do touch, parts that must not touch are apart by at least the stated clearance, and the pack slides out, lifts and comes away with nothing in its path. All 57 pass.

## Decision

*Table 1. Changes made to the model, the BOM and the calculations.*

| # | Problem in the concept | Change made | Why this way |
| --- | --- | --- | --- |
| P1 | The cradle base was a flat 4 mm plate whose "saddle" block cut 6 mm into the down tube; nothing could seat it on a round tube. | Three V-saddles (40 mm lengths of 35 x 12 mm aluminium bar, a 120 degree V with a 1.5 mm rubber liner) under a tray folded from 3 mm 5052 aluminium. Each saddle is held by two M5 countersunk screws through the tray. | A V seats on any round tube from 28 to 32 mm (R5) and lets the band press the cradle on squarely. Aluminium instead of the concept's folded steel keeps the cradle at 1.10 kg; in steel the tray alone would have weighed about 1.3 kg and R6 would fail. |
| P2 | The two band clamps were drawn as rings round the tube that passed through the base; a band cannot go through a plate. | Each band passes down through a pair of 3 x 13 mm slots in the tray, round the V-saddle and the underside of the tube, and back over the tray; the worm screw sits under the tube. Three band clamps (at the middle and 100 mm each side) instead of two. | This is how a band holds a plate to a tube without drilling the frame. A real band wraps only about 150 degrees of the tube, not a full turn, so with two bands the 25 g rotation margin would fall from 1.40 to about 0.96; three bands give 1.44 (SSP-CAL-001 v0.3 section 8). |
| P3 | The end stop was a solid 30 x 104 x 90 mm block with the receptacle drawn inside it. | A folded 3 mm aluminium end stop: a wall with an open-topped notch for the pack's plug, a foot on the tray and two side flanges bolted inside the guides. The bought SwapCell receptacle bolts behind the wall on four M4 bolts; the plug stops 1 mm short of its bottom. The guides are the tray's own folded side tabs. | Every part is sheet that can be cut, folded and drilled by hand. Held on three edges, the wall sees about 62 MPa at 25 g, a factor of 3.1 on yield. The open notch avoids a thin strip of metal spanning the window. |
| P4 | The V1 lever was three loose blocks (hinge, pad and handle, up to 5 mm apart), its pad 4 mm short of the pack, and the hinge block stood across the pack's path, so the pack could not slide out. | A drop-down gate (3 mm steel) on a stainless butt hinge at the tray's top end, with a 3 mm rubber pad that presses the pack's top end below the handle, closed by a bought adjustable over-centre draw latch with a safety catch on a folded ear on the tray's left side; the latch hook pulls a keeper on the gate's folded flange. Opened, the gate folds flat under the pack's path. | Keeps latch class V1: an over-centre lever, 330 N preload (the latch pulls about 314 N), a detent (the safety catch). Nothing stands in the pack's path once the gate is down. One hinge and one latch, both bought. |
| P5 | The slide rails were solid steel bars with no fixing; the latch catch was a loose block. | Two 12 x 10 mm HDPE slide strips on three self-tapping screws each from under the tray; a 10 x 6 mm steel catch bar on two M4 countersunk screws. | Low friction for the pack, no screw heads on the sliding faces; the pack's latch still sits 3 mm short of the catch. |
| P6 | The host adapter floated 4 mm above the tube beyond the end of the base. | The tray runs 70 mm past the end stop and the adapter sits on it, two M4 screws up into its inserts, with a short lead to the receptacle. | Uses the tray; keeps the adapter where the concept put it, 7.5 mm clear of the chainring. |
| P7 | The torque arms passed 2 mm into the fork blades; their clips were rings on the blades not joined to the arms; the fork had no dropouts and the axle was shorter than its nuts needed. | Joggled arms from 20 x 5 mm steel bar: a 10 mm slot open at the end that fits the axle flats and lies flat on the outside of the dropout under the washer and nut, and an 8 mm joggle so the long part lies on the outside of the blade, held 130 mm up by one band clamp round blade and arm. The donor's 6 mm dropouts with 10 mm slots and a 150 mm axle are now in the model. | The arm bears on the dropout face and the blade, as a torque arm must, and can be made with a hacksaw, file and vice. The lever arm stays 130 mm, so SSP-CAL-001 section 7 is unchanged. |
| P8 | The controller floated 4 mm in front of the seat tube with no fixing. | A 4 mm rubber pad on the front of the seat tube and two 12 mm band clamps round the tube and the controller case. | No drilling of the frame; the pad stops the case rattling and chafing the paint. |
| P9 | The pedal-assist disc sat on nothing (its bore was 36 mm on a 16 mm spindle), touched the left chainstay, and there was no Hall sensor. | A split disc that clamps on the spindle 10 mm outboard of the bottom bracket shell, and the Hall sensor on a ring bracket that fits under the left lockring, 2.5 mm from the magnets. The chainstays now meet the shell, not the space beside it. | This is how bolt-on pedal-assist sensors fit a cup-and-cone bottom bracket; the crank comes off but the spindle stays. |
| P10 | The handlebar display box cut 2.5 mm into the bar; the brake sensors were boxes centred on the grip section of the bar. | The display on its own bar clamp left of the stem; each brake sensor on a small bar clamp inboard of its lever, with a magnet glued to the lever's pivot post. | Fits rod or cable levers without changing them. It also puts the sensors where the appearance model (`cad/src/product_model.py`) already showed them (review note, 2026-09-26, proposal 3). |
| P11 | The harness ran through open space and through the cradle. | Routed along the left side of the down tube near the bottom bracket, the seat tube, the top tube and the head tube, down the front of the left fork blade (over the torque arm's band) and up the stem; cable ties every 150 mm; the 20 A fuse holder on the lead from the adapter. | Every run lies on a tube, clear of the cradle, wheel, cranks and chainring by the checked distances. |
| P12 | The panel stand's legs ran 14 to 22 mm into the panel, nothing joined the leg tops, nothing held the panel, and the charger floated. | A timber A-frame from 45 x 45 mm sawn timber: two top rails under the panel at its 15 degree tilt, two tall rear and two short front legs lapped on the rails' outside faces with M8 coach bolts, two low braces and two cross battens. The panel bolts through its own frame holes into the rails; the charger screws to the left rear leg in the panel's shade. | The BOM allowed steel angle or timber; timber needs no welding and only a saw and drill, and matches the appearance model (review note, 2026-09-26, proposal 4). |
| P13 | The front wheel's spokes ran from the hub centre through the motor shell. | Spokes from the motor's two flanges to the rim (context only). | Shows the wheel as a mechanic laces it. |

*Table 2. Knock-on changes.*

| Item | Change | Reason |
| --- | --- | --- |
| Pack position | The V-saddles lift the pack 7 mm; it still sits at 48 % of the down tube. Clearance in the triangle 121 mm (was 123 mm); free travel 165 mm for the 143 mm needed. | Follows P1. |
| Swap sequence | Open the latch, fold the gate down, press the pack's release and slide the pack 143 mm up the tube, lift 45 mm, take it out to the left. Fitting is the reverse. | Follows P4; the concept did not state one, and its own lever blocked the pack. |
| Mass | Kit 3.93 kg (was 3.80 kg); added mass with pack 6.78 kg, 0.22 kg under R6's 7 kg (SSP-CAL-001 v0.3 section 2). | P1 to P8. |
| Retention | Axial margin at 25 g 7.7 (was 6.8); rotation margin 1.44 (was 1.40); end stop factor 3.1 on yield. | P1 to P4. |
| Cost | BOM line 2 USD 6 (now a made part), line 4 USD 28 to 33, line 12 USD 10 to 14, line 14 USD 8 to 11. Bike kit USD 196 (was USD 188), USD 54 under the USD 250 value-engineering target; solar set USD 90 (was USD 86). | Parts added for construction. |
| Drawings | SSP-DWG-001 Rev P3; making sketches SSP-DWG-101 to 110 added. | Follows the model. |
| Documents | SSP-CAL-001 v0.3, SSP-REQ-001 v0.5, SSP-PRC-001 v0.5: mass, cost, retention and fit figures updated. No requirement changed status. | Follows the model. |
| Unchanged | Motor, torque arm lever arm, controller, pack, charging, solar yield, range, hill climb and braking results (each within rounding of v0.2). | |

*Table 3. Proposed, then accepted by Amish as recommended on 2026-10-02.*

| # | Question | Options | Recommendation |
| --- | --- | --- | --- |
| A1 | The pack swap now has two hand movements at the cradle (open the latch, fold the gate) where the concept showed one lever. | (a) gate and draw latch as modelled; (b) design a single lever that also folds the gate (a linkage, more parts, not yet designed). | (a) for the prototype; review after the first swap trials at TRL 4. **Decided 2026-10-02: (a).** |
| A2 | Timber for the panel stand (also proposal 4 of 2026-09-26). | (a) timber, as modelled; (b) steel angle, bolted. | (a): no welding, local materials, and it is what the renders show. **Decided 2026-10-02: (a).** |

## Consequences

- `design_state: constructable` in `project.yaml`. The build plan SSP-BLD-001 shows every component and step in pictures generated from the model (`cad/src/build_plan_media.py`); the decisions are recorded in the design decisions register SSP-DEC-001.
- Requirement status is unchanged: none not met; R3, R4 and R11 at risk; R7, R9, R10 and R13 not verifiable at TRL 3; the rest met on paper (SSP-CAL-001 v0.3).
- The photoreal renders (`media/render-*.png`), `media/card.png`, `media/social-preview.png` and the appearance model `cad/src/product_model.py` still show the concept cradle, lever, torque arms and stand; they need updating on Amish's Mac, where Blender is.
- The fork must take the motor's 10 mm axle flats without filing (decided on 2026-10-02: the fork is never filed for now, SSP-DEC-001); the build plan asks for a donor fork that does.

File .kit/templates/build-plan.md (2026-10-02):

---
doc_id: PRJ-BLD-001
title: Project prototype build plan
project: Project name
doc_type: Build plan
version: "0.1"
status: Draft
date: YYYY-MM-DD
author: Amish Chadha
license: CERN-OHL-S-2.0
revisions:
  - version: "0.1"
    date: YYYY-MM-DD
    author: Amish Chadha
    change: First build plan; design made constructable
---

# Project prototype build plan

**Plan, not yet built.** How to build the first proof-of-concept prototype, component by component. Building and testing to it is TRL 4 work. Decisions still to be made are kept in the design decisions register (`docs/06-design-decisions.md`), not here.

## 1. What you are building

Every component, pulled apart and numbered in build order

One short paragraph: what the prototype is, how many components, which are made and which are bought, and the main ways they are made.

## 2. What changed to make it buildable

| Component | The concept had | The buildable design has | Why |
| --- | --- | --- | --- |

## 3. Making the components

### 3.1 Component name

Making sketch

**What it is and what it is made from.**

**How to make it.**

1. Mark out ...
2. Cut ...

**How it fits the parts next to it.**

Close-up of the joint

**Check before moving on.**

## 4. Putting it together

### Step 1: ...

Step 1

## 5. First checks

| Check | Requirement | How | Pass when |
| --- | --- | --- | --- |

## 6. Safety stops

## 7. Tools, skills and workspace

## 8. Where the numbers come from

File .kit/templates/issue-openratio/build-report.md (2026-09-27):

---
name: Build report
about: Tell us what happened when you built, printed or tested part of this design
title: "Build report: "
labels: build-report
---

This is a research and educational prototype, not a medical device. It is a TRL 3 concept and is not released for fabrication. If you build any part of it, you do so at your own risk. Reports help everyone.

**What you built** (part, sub-assembly or test)

**Materials, tools and settings**

**What worked**

**What did not work, with photos or measurements if you have them**

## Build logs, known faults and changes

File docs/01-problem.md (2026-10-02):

---
doc_id: SSP-PRB-001
title: SunSpoke problem statement
project: SunSpoke
doc_type: Problem statement
version: "0.4"
status: Draft
date: '2026-10-02'
author: Amish Chadha
license: CERN-OHL-S-2.0
revisions:
- version: "0.1"
  date: '2026-09-24'
  author: Amish Chadha
  change: Initial scaffold
- version: "0.2"
  date: '2026-09-24'
  author: Amish Chadha
  change: Populate to TRL 2 (users, context, constraints, out of scope, prior work)
- version: "0.3"
  date: '2026-09-25'
  author: Amish Chadha
  change: Record SSP-DDR-001 (48 V on SwapCell, budget covers the bike kit only, pack priced in SwapCell); add checked sources to prior work
- version: "0.4"
  date: '2026-10-02'
  author: Amish Chadha
  change: "First region and partner type decided by Amish on 2026-10-02 (SSP-DEC-001)"
---

# SunSpoke problem statement

Most bicycles in rural sub-Saharan Africa are unpowered steel roadsters that carry people, water, firewood and goods over long, rough, hilly routes, and the electric alternatives on sale are either a whole new e-bike or a closed kit that local mechanics cannot repair and that assumes grid charging. Design with, not for: requirements must come from co-design sessions and field trials with the intended users through a local partner.

## The problem

The heavy single-speed roadster (28 in wheels, steel frame, rod or cable brakes, strong rear carrier) is the working vehicle of rural East, Central and Southern Africa and of many low-income regions elsewhere. Riders routinely carry 30 to 80 kg of goods or a passenger over 10 to 30 km a day on dirt roads. The limit is the rider's own power: hills and loads turn a 20 km trip into hours of walking and pushing.

Electric assist solves this, and e-bikes and conversion kits are already sold in the region. Three gaps remain:

1. **Fit.** Most kits are designed for modern aluminium bikes with 26 or 29 in wheels, disc brakes and threaded bottle-cage bosses. Roadsters have 28 in (ETRTO 635) rims, narrow steel dropouts, rod brakes and no mounting bosses. Buying a new e-bike to get assist throws away a bike the owner already has.
2. **Repair.** Closed kits use proprietary connectors, sealed displays and controller settings that need a laptop or app. When a part fails, the bike is parked until a spare arrives from a city. The roadside bicycle mechanic, who keeps every other bike running, is locked out.
3. **Charging.** Grid power is absent or unreliable in much of the rural region. Charging at a shop in town costs money and a trip. A single 100 W panel or a shared village charging hub could supply enough energy, but kits are not designed around slow solar charging.

SunSpoke is an open, bolt-on conversion kit that fits the roadsters people already own, can be fitted and repaired by a local bike mechanic with basic tools, and charges from one 100 W panel or a shared hub using a SwapCell-compatible pack.

## Users and context

| User | Need | Context |
| --- | --- | --- |
| Rural commuter | Reach work, school or market 10 to 30 km away without arriving exhausted | Dirt and gravel roads, hills, daily use |
| Small trader | Carry 30 to 80 kg of produce, water or goods to market, sometimes a passenger | Loaded rear carrier, stop-start riding, heat |
| Community health worker | Reliable daily rounds to scattered households with a medical kit | Long distances, schedule matters, often alone |
| Local bike mechanic | Fit, maintain and repair the kit with the tools and parts already in the shop, and earn from it | Roadside or market stall, hand tools, no welding in many cases |
| Village charging hub operator | Charge several packs a day from a shared solar array and track their condition | Hub with panels, dock and shade |

### Operating environment

- **Roads:** murram (laterite), gravel, sand and rutted dirt, with potholes, washboard and grades up to about 10 % on short climbs.
- **Loads:** rider 60 to 80 kg plus 30 to 80 kg on the carrier; bike about 20 to 23 kg before conversion.
- **Climate:** ambient 15 to 40 °C, with surfaces in sun reaching 60 °C or more; dust in the dry season; heavy rain, mud and shallow water crossings in the wet season.
- **Power:** limited or no grid; solar resource of about 4 to 6 peak sun hours per day across most of the region, lower in the rains.
- **Supply chain:** bicycle spares, generic e-bike parts and motorcycle electrical parts are available in towns; specialist parts are not.

## Constraints

- Garage-buildable prototype: the bike conversion kit costs $250 USD or less in parts. The solar charging set is costed separately, and the SwapCell pack is priced once in the SwapCell repo and excluded (decided by Amish, 2026-09-25; SSP-DDR-001).
- Bolt on to the donor bike with no welding, frame drilling or cutting.
- Fitting and repair possible with the tools a roadside bike mechanic already has.
- Standard, pluggable connectors and generic parts wherever possible, so a failed part can be swapped with one from the local market.
- Legal and safe assist: 250 W rated power and an assist cutoff speed in line with pedelec practice (in the EU, 250 W and a 25 km/h cut-off under Regulation (EU) No 168/2013, with EN 15194 as the product standard); SunSpoke defaults to 20 km/h (decided, SSP-DDR-001). National rules in target countries are still to be checked.
- Uses SwapCell interface v0.3 so packs can be shared across portfolio vehicles and charged at SwapCell docks. The system is 48 V on SwapCell (decided by Amish, 2026-09-25; SSP-DDR-001).

## Out of scope

- Building or selling complete bicycles.
- Designing the battery pack itself (that is SwapCell).
- The village charging hub and its dock (SwapCell and PowerBox cover these).
- Motorcycle-class speed or power (over 250 W rated or assist above 25 km/h).
- Cargo tricycles and trailers (see CargoMule and FlatTrike).

## Prior work

- **Commercial conversion kits.** Front hub, rear hub and mid-drive kits with 36 V and 48 V batteries are sold worldwide and in regional markets. They prove the technology and set the price floor, but are not designed for 28 in roadster wheels, rod brakes or local repair.
- **Regional e-bike ventures.** Several companies in East Africa assemble or sell e-bikes and electric motorcycles, some with battery swapping. They show demand and a working swap model, but most are closed products that need their own service network.
- **Rugged bicycles for rural use.** Purpose-built heavy-duty bicycles such as the World Bicycle Relief Buffalo bicycle show that design for rural loads and a single mechanic training curriculum works. World Bicycle Relief describes a heavy-gauge steel frame that carries 220 lb (about 100 kg) on the rear carrier, with frame, carrier, stand and wheels shared across models ([World Bicycle Relief, "The Bike"](https://worldbicyclerelief.org/the-bike/), checked 2026-09-25).
- **Pedelec rules.** In the EU a pedal cycle with assist up to 250 W that cuts off by 25 km/h is excluded from motor-vehicle type approval under Regulation (EU) No 168/2013 ([Wikipedia, "Pedelec"](https://en.wikipedia.org/wiki/Pedelec), checked 2026-09-25; secondary source). Rules in the first target country are not yet checked.
- **Bicycle taxis (boda-boda).** Bicycle taxis in East Africa show how much load and distance a roadster is asked to carry, and how important a local repair economy is.
- **Solar charging for small vehicles.** Solar e-bike charging stations and off-grid battery hubs exist in pilot form. The first-order numbers in SSP-PRC-001 show one 100 W panel can cover a typical day of assisted riding.

Two sources were checked on 2026-09-25 (above). The other entries are general descriptions without named sources; they stay unverified until a named source is checked.

## Open questions

- Which partner organization and which region first (for example an East African bike mechanic cooperative, a health worker program, or a university engineering department)? Decided 2026-10-02: western Kenya and eastern Uganda as the default region, where 28 in roadsters and bicycle taxis are common, with a bicycle mechanics' group or rural transport organization there as the partner type; the partner is named when the portfolio picks partners for this area (SSP-DEC-001).
- The 48 V system is decided (SSP-DDR-001). Field work should still record how common 36 V and 48 V spares are locally, which bears on the later 36 V low-cost variant.
- How much cargo and passenger carrying must the kit support, and does the pack location need to leave the rear carrier free? Assumed yes; to validate.
- What assist speed limit and registration rules apply in the first target country?

## Safety

> **Safety:** A conversion adds a lithium-ion pack of about 468 Wh, more speed and more mass to a bicycle with weak rod brakes and an old steel fork. The hazards (pack fire, dropout failure, braking, wet connectors) are set out in SSP-PRC-001.

## User research and co-design

This design is for communities the author is not part of, so requirements come from the people who will use it.

- [ ] Identify a local partner organization (Helpful Engineering network, NGO or university)
- [ ] Run co-design sessions with intended users; record who, where and what was learned
- [ ] Validate load, distance, terrain and cost assumptions in the field
- [ ] Revise requirements (REQ) from findings before freezing the design

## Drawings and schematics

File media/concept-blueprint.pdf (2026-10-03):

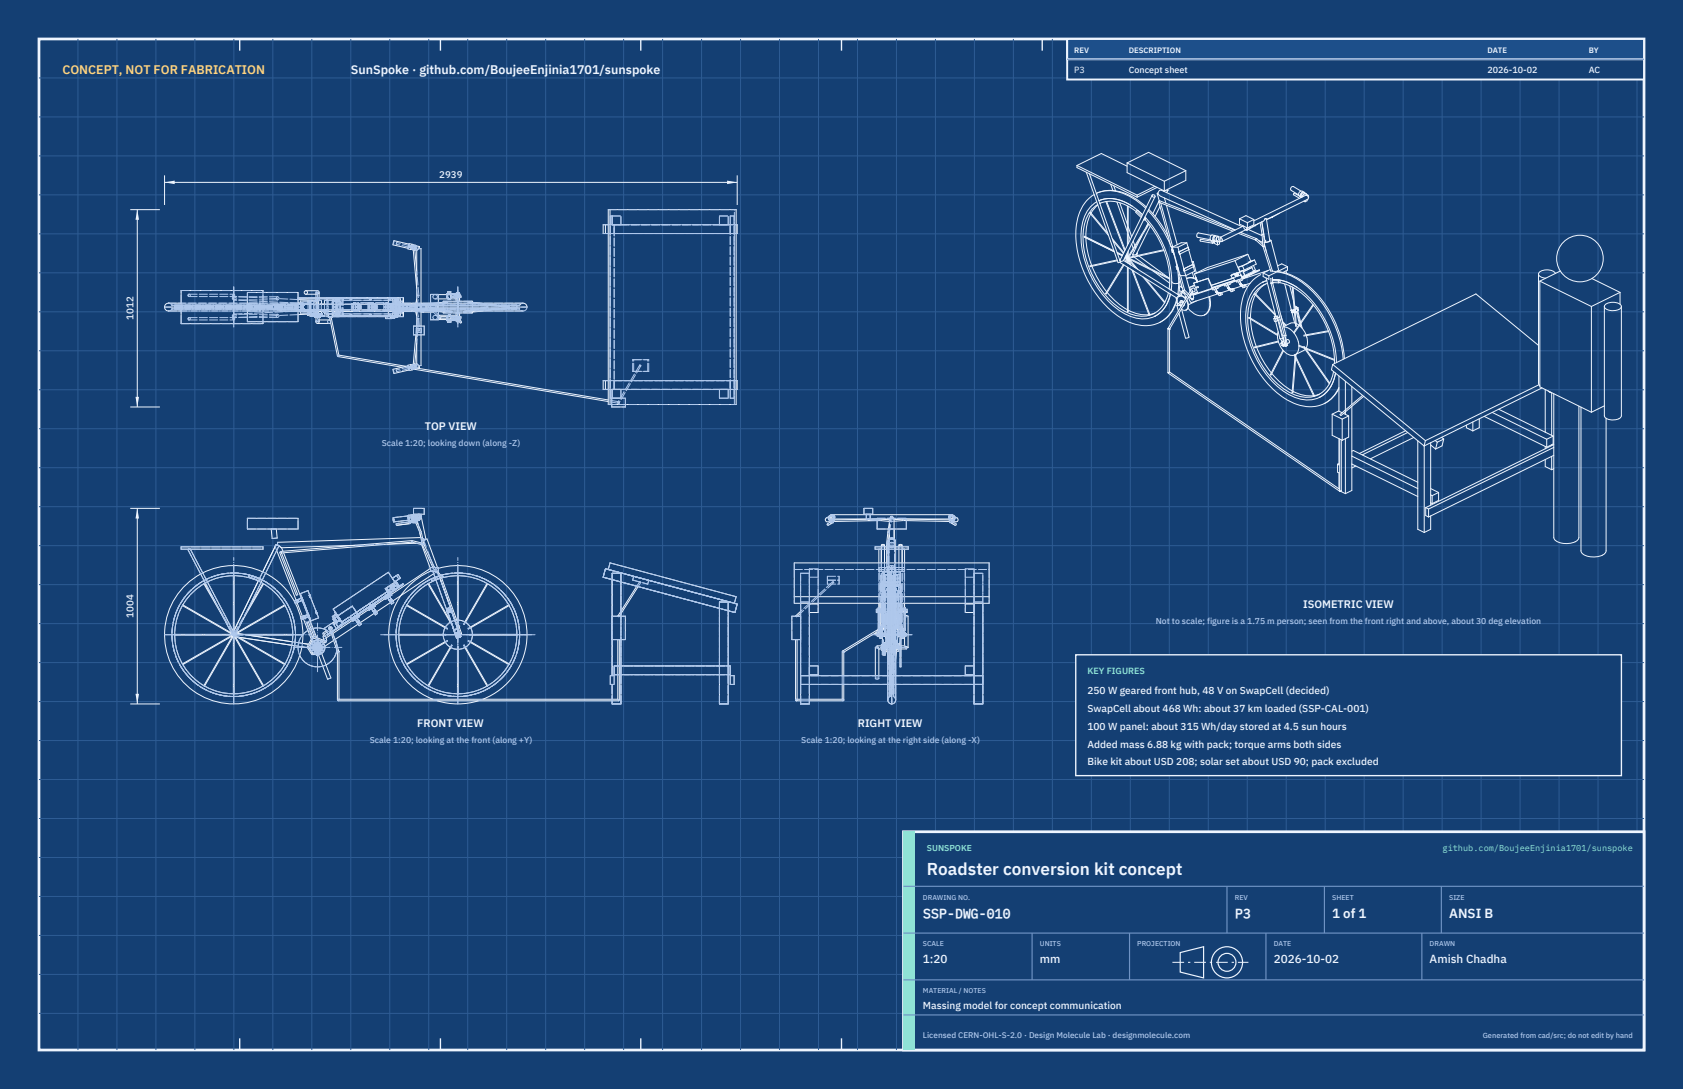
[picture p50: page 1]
CONCEPT, NOT FOR FABRICATION; SunSpoke · github.com/BoujeeEnjinia1701/sunspoke; FRONT VIEW; TOP VIEW; RIGHT VIEW; ISOMETRIC VIEW; REV; DESCRIPTION; DATE; Concept sheet; SUNSPOKE; github.com/BoujeeEnjinia1701/sunspoke; DRAWING NO. SSP-DWG-010; REV P3; SHEET 1 of 1; SIZE ANSI B; SCALE 1:20; UNITS mm; PROJECTION; DRAWN Amish Chadha; Licensed CERN-OHL-S-2.0 · Design Molecule Lab · designmolecule.com; Generated from cad/src; do not edit by hand

Scale 1:20; looking down (along -Z)

Not to scale; figure is a 1.75 m person; seen from the front right and above, about 30 deg elevation

KEY FIGURES
250 W geared front hub, 48 V on SwapCell (decided)
SwapCell about 468 Wh: about 37 km loaded (SSP-CAL-001)
100 W panel: about 315 Wh/day stored at 4.5 sun hours
Added mass 6.88 kg with pack; torque arms both sides
Bike kit about USD 208; solar set about USD 90; pack excluded

Scale 1:20; looking at the front (along +Y)

Scale 1:20; looking at the right side (along -X)

Roadster conversion kit concept

MATERIAL / NOTES
Massing model for concept communication

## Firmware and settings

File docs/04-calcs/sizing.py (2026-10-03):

"""SunSpoke sizing calculations for SSP-CAL-001 (TRL 3).

Run from the repo root:  python docs/04-calcs/sizing.py
Prints every number quoted in docs/04-calcs/01-sizing.md and writes
docs/04-calcs/results.csv with the requirement status table.

First-principles estimates on paper. Every input is an assumption stated below;
nothing here is measured. SwapCell values follow SwapCell interface v0.3 and
SWC-CAL-001 (swapcell repo).
"""
import csv
import math
from pathlib import Path

ROOT = Path(__file__).resolve().parents[2]
G = 9.81
RHO_AIR = 1.2

# ---------------------------------------------------------------- assumptions
# Design load case (SSP-REQ-001)
RIDER, CARGO, BIKE = 75.0, 25.0, 22.0          # kg

# Kit mass (kg), estimates; pack from SWC-CAL-001
KIT_MASS = {
    "Motor wheel, increase over the donor front wheel": 1.20,
    "Torque arms (pair) and band clamps": 0.28,
    "Controller, rubber pad and two band clamps": 0.55,
    "SwapCell receiver cradle, three band clamps, gate and draw latch": 1.10,
    "Host adapter and charge port": 0.15,
    "Pedal-assist sensor": 0.10,
    "Handlebar control and brake sensors": 0.15,
    "Wet-weather brake blocks, 4 (they replace the donor blocks; counted in full to be safe)": 0.10,
    "Wiring harness and fuse": 0.40,
}
PACK_MASS = 2.85                                # kg, SWC-CAL-001

# SwapCell pack (SWC-CAL-001, interface v0.3)
PACK_WH_NOM = 466.0          # Wh at 0.2C, nominal cells
PACK_WH_MIN = 452.0          # Wh at 0.2C, cells at datasheet minimum
PACK_V = 46.8
PACK_R = 0.110               # ohm
USABLE = 0.90                # usable window (10 to 100 %)
LEGACY_A = 15.0              # A, legacy discharge-only limit (no heartbeat)
PACK_CHG_LIMIT_A = 5.0       # A, standard allowed charge current

# Road and rider
CRR = 0.020                  # dry dirt road
CDA = 0.60                   # m^2
V_CRUISE = 18.0              # km/h
ALLOW = 1.30                 # hills, rough surface, stop-start
P_RIDER_CRUISE = 70.0        # W
P_RIDER_CLIMB = 80.0         # W
ETA_DRIVE = 0.75             # motor plus controller, cruise
WHEEL_R = 0.355              # m, 28 in (ETRTO 635) tyre outer radius
ASSIST_LIMIT = 20.0          # km/h, decided default (SSP-DDR-001)

CASES = {  # name: (cargo kg, Crr, allowance, speed km/h)
    "Design (25 kg cargo, dirt)": (25.0, 0.020, 1.30, 18.0),
    "Light (no cargo, graded murram)": (0.0, 0.015, 1.20, 18.0),
    "Heavy (80 kg cargo, rough dirt)": (80.0, 0.025, 1.30, 15.0),
}

# Hill (R3)
GRADE = 0.08
V_CLIMB = 8.0                # km/h
CLIMB_LEN = 500.0            # m
T_AMB_HOT = 35.0             # C
# Motor model: 250 W geared hub, 48 V, slow winding (about 200 rpm no-load at 48 V)
NOLOAD_RPM = 200.0
GEAR_EFF = 0.90
R_WIND = 0.45                # ohm, line to line, warm
P_IRON = 15.0                # W, iron, gear and bearing losses (assumption)
C_TH = 600.0                 # J/K, stator and winding heat capacity
R_TH = 1.2                   # K/W, winding to ambient while riding
T_WIND_LIMIT = 120.0         # C, practical limit for small geared hubs with nylon gears
MOTOR_PEAK_NM = 40.0         # N m at the wheel, typical 250 W geared hub
# Thermal derate on the motor thermistor (SSP-DDR-002, decided 2026-09-25)
T_DERATE_START = 110.0       # C, controller starts reducing current

# Solar (R8)
PANEL_W, SUN_H, SUN_H_LOW, DERATE = 100.0, 4.5, 4.0, 0.80
ETA_MPPT, ETA_CELL_CHG, ETA_PACK_OUT = 0.92, 0.95, 0.97
CHARGE_V = 50.0              # V, mid-charge pack voltage
LOAD_ON_W = 4.0              # W, display and lights while charging in mode 4

# Fork and torque arms (R10)
FLAT_LEVER = 0.005           # m, effective lever of the axle flats on each dropout
ARM_LEVER = 0.130            # m, axle to torque arm clamp
ARM_W, ARM_T = 20.0, 5.0     # mm plate width and thickness
STEEL_YIELD = 250.0          # MPa, mild steel
MOTOR_FLATS = 10.0           # mm across flats
DROPOUT_SLOT = 9.53          # mm, 3/8 in roadster slot (assumption, to survey)

# Cradle retention (interface v0.3 item V, class V1), constructable design (SSP-DDR-003):
# three band clamps, each through two slots in the tray, round a 120 degree V-saddle and the tube
CRADLE_MASS = 1.10           # kg, from the model volumes plus bought parts (SSP-DDR-003)
N_BANDS = 3
V_HALF = math.radians(60.0)  # half angle of the V-saddle, from the vertical
LINER = 1.5                  # mm, rubber liner in the V
SADDLE_HALF_W, SADDLE_H, SADDLE_LAND = 17.5, 12.0, 4.0   # mm
RECEIVER_DESIGN_PACK = 3.5   # kg, SwapCell receiver design mass
VIB_G, SHOCK_G = 8.0, 25.0
BAND_T = 1500.0              # N, worm-drive band tension at 3 to 4 N m screw torque
MU_LINER = 0.40              # rubber liner on painted steel
TUBE_R = 0.0143              # m, 28.6 mm down tube
CG_OFFSET = 0.077            # m, pack plus cradle centroid above the down tube axis (70 mm, plus 7 mm for the V-saddles)
HAND_F = 50.0                # N
PRELOAD = 330.0              # N, SwapCell V1 receiver preload

# Braking (R11)
V_BRAKE = 20.0               # km/h
T_APPLY = 0.5                # s, lever travel and linkage delay
STOP_TARGET = 9.0            # m
PAD_N = 250.0                # N clamp per pad from a 100 N hand force on rod levers
MU_DRY, MU_WET = 0.40, 0.12  # standard block on steel rim, dry and wet
MU_WET_BLOCK = 0.25          # assumed wet friction of wet-weather blocks for steel rims (SSP-DEC-001, 2026-10-02); replace with the maker's data or the TRL 4 wet braking test
WET_TARGET = 14.0            # m, R11 wet target from 20 km/h on a wet dirt road with wet-weather blocks (proposed value, 1.5 x the dry target)
R_RIM = 0.310                # m, braking surface radius

# INTERLOCK wake (item W)
V_SLEEP, R_PULLUP, R_CODE = 3.3, 100e3, 10e3

OUT = {}


def put(key, value, fmt="{:.2f}"):
    OUT[key] = value
    print(f"  {key:58s} {fmt.format(value)}")


def section(t):
    print(f"\n== {t}")


def road_force(m, crr, v_kmh, grade=0.0):
    v = v_kmh / 3.6
    th = math.atan(grade)
    return (m * G * math.sin(th), crr * m * G * math.cos(th), 0.5 * RHO_AIR * CDA * v * v)


# ---------------------------------------------------------------- mass
section("Mass (R6)")
kit = sum(KIT_MASS.values())
added = kit + PACK_MASS
m_design = RIDER + CARGO + BIKE + added
put("Kit mass without pack, kg", kit)
put("Added mass with pack, kg", added)
put("Design load case total, kg", m_design)
put("R6 margin to 7 kg, kg", 7.0 - added)
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

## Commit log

2026-09-24 Initial scaffold: standard open hardware layout, CERN-OHL-S v2 + MIT licenses
    Claude-Session: https://claude.ai/code/session_01XuhhSU4W6fYhgCfURbrkut
    [bom.csv]
2026-09-25 Adopt portfolio kit v1.3.0: session commands, scale figure, 3D viewer, flow diagrams
    Adds .claude/commands (/populate, /advance-trl3, /rein-in, /refresh-media)
    so every Claude Code session starts from the standard prompts, and extends
    concept media with a 1.75 m scale figure, an interactive glTF viewer and
    system or energy flow diagrams. TRL cap 3 unchanged.
    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
2026-09-25 Kit v1.3.1: renderer fixes from the TremorTrace pilot
    Context scale parts for small objects, cutaway exclusions, and text
    labels in flow diagrams.
    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
2026-09-25 Populate sunspoke to a strong TRL 2 with concept media (batch 2)
    Problem, requirements and precis v0.2, massing model and concept media,
    indicative BOM, docs/REVIEW.md with decisions proposed and awaiting Amish.
    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
    [bom.csv]
2026-09-25 Advance sunspoke to TRL 3 (batch 2)
    Decisions approved by Amish 2026-09-25 recorded in DDR-001. TRL 4 is on hold.
    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
    [bom.csv, results.csv, sunspoke-assembly.step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]
2026-09-26 Accept all recommendations (DDR-002), switch footer to designmolecule.com, add README write-up with new inspiration point
    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
    [bom.csv, results.csv, sunspoke-assembly.step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]
2026-09-27 Product appearance model and photoreal renders
    Adds cad/src/product_model.py (appearance model for renders only, all main
    dimensions from model.py) and Blender renders in media/render-*.png,
    captioned with the project, repository and viewing direction. README leads
    with the product render; trl stays 3.
    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
2026-10-01 Image quality pass: legible exploded views, flow diagrams and drawing sheets
    Kit 1.6.1 image layout: the parts list sits in its own column, number bubbles sit on visible parts and never overlap, small parts get a leader, pictures are cropped to the subject, flow labels keep numbers with their units, and sheet captions and the revision table no longer overprint. Concept images, blueprint and general arrangement sheet regenerated; repo-specific labels moved clear of other text and lines.
2026-10-02 Kit 1.7.0: constructable design, illustrated build plan and design decisions register
    The design is now constructable: every part can be made and fits its neighbours, with each change recorded in a Design for construction decision record (made under Amish's 2026-09-30 instruction; ope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
    FlexHand also credits Dr. Geeti Chadha as a contribut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
    [bom.csv, results.csv, sunspoke-assembly.step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]
2026-10-02 Record Amish's approval of the open-decision recommendations
    Amish approved the recommendation on every open decision in the design decisions register ("i approve your recommendations for all 555 open decisions.", 2026-10-02). Each decision is moved to Decisio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
2026-10-03 Carry approved follow-ups into the design and redo photoreal renders
    Amish approved the follow-up actions from the open-decision sign-off ("APPROVED CHANGES, COMPLETE THESE", 2026-10-02), the design-for-construction change tables in ten repos, the last wave's open dec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
    [bom.csv, results.csv, sunspoke-assembly.step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]

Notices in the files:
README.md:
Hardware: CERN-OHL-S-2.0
